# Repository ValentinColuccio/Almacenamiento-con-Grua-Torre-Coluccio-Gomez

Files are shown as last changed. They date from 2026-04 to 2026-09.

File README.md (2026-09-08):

<div align="center">

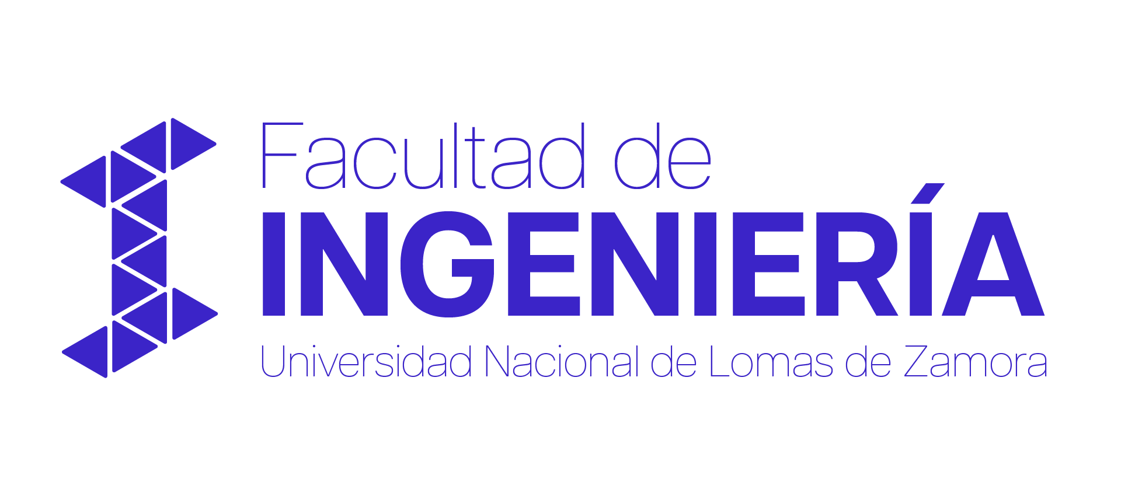
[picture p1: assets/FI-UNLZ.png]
Logo FI UNLZ


<h2 align="center">Facultad de Ingeniería – Universidad Nacional de Lomas de Zamora</h2>

# 🏗️ Grúa Torre Robótica Inteligente

### Proyecto Final de Carrera | Ingeniería en Mecatrónica





</div>

---

> 📄 **[Leé primero el Brief](Doc/Brief.md)** — de qué se trata el proyecto y
> cuál es su finalidad, explicado sin contenido técnico.

---

## 📑 Índice

- [🧠 Descripción General](#-descripción-general)
- [📸 Galería y Demostraciones](#-galería-y-demostraciones)
- [🚀 Arquitectura del Sistema](#-arquitectura-del-sistema)
- [🔍 Decisiones de Ingeniería](#-decisiones-de-ingeniería)
- [💰 Costos del Proyecto](#-costos-del-proyecto)
- [🔌 Hardware y Esquema de Conexiones](#-hardware-y-esquema-de-conexiones)
- [📡 Protocolos de Comunicación](#-protocolos-de-comunicación)
- [📐 Cinemática y Control Embebido](#-cinemática-y-control-embebido)
- [⚙️ Funcionalidades Clave](#️-funcionalidades-clave)
- [🛠️ Tecnologías Utilizadas](#️-tecnologías-utilizadas)
- [📂 Estructura del Repositorio](#-estructura-del-repositorio)
- [🙏 Agradecimientos](#-agradecimientos)
- [👤 Autores](#-autores)

---

## 🧠 Descripción General

Este repositorio contiene el desarrollo integral (software, hardware, planos y documentación) de una **grúa torre robótica a escala**, presentada como Proyecto Final de Carrera para la carrera de **Ingeniería en Mecatrónica** en la Universidad Nacional de Lomas de Zamora (UNLZ).

El sistema simula un entorno logístico automatizado de alta complejidad. Integra hardware embebido, modelado cinemático tridimensional e Inteligencia Artificial distribuida para lograr un ciclo autónomo de:

1. **Percepción:** Detección y clasificación de objetos en tiempo real mediante visión artificial.
2. **Decisión:** Reconocimiento de comandos de voz e interpretación de órdenes, y gestión lógica de inventario.
3. **Actuación:** Movimiento coordinado de precisión para la manipulación, almacenamiento y entrega de cargas. El diseño mecánico contempla diferentes mecanismos de transmisión, empleando reducción por engranajes para el eje principal (Motor A) y transmisión por cable para el resto de los ejes de la estructura.

> **Evolución Tecnológica:** La arquitectura de control de bajo nivel fue optimizada utilizando un microcontrolador **ESP32** bajo un paradigma de programación estructurada y modular. Esto garantiza una ejecución determinista de tiempo real para el manejo simultáneo de 4 actuadores paso a paso con velocidades independientes.

---

## 📸 Galería y Demostraciones

El proyecto cuenta con un diseño de ingeniería respaldado por modelos CAD y esquemas electrónicos, disponibles en este repositorio.

<div align="center">
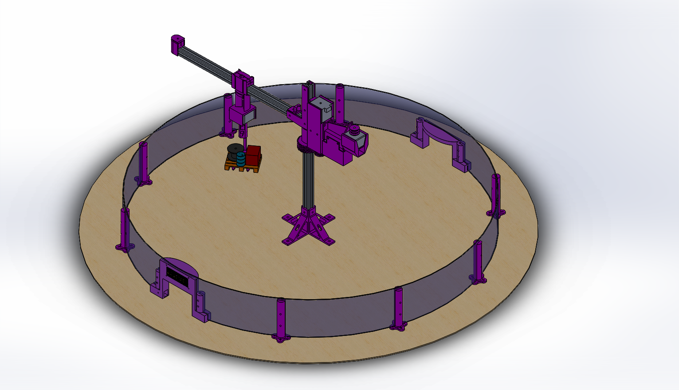
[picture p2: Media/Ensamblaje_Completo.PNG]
Ensamblaje Completo 3D
  
  <br>
  <em>Render del ensamblaje mecánico completo de la grúa torre.</em>
</div>

<br>

<div align="center">
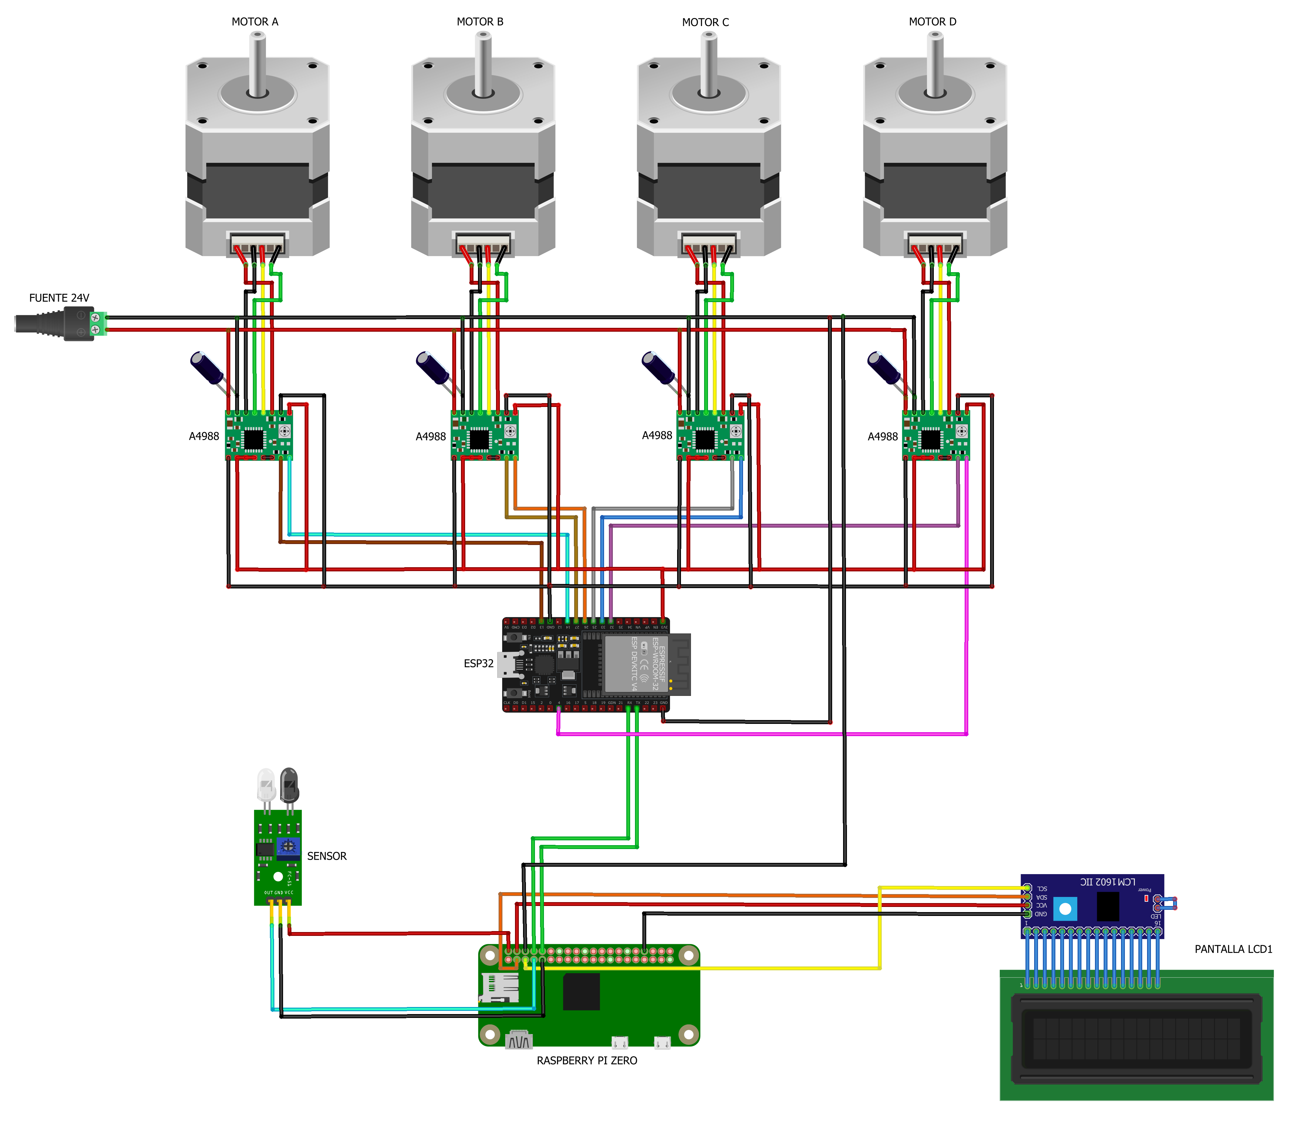
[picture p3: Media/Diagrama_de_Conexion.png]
Esquema Electrónico
  
  <br>
  <em>Esquemático del circuito de potencia y control (Integración de ESP32, Drivers A4988, Raspberry Pi, Sensor, Pantalla LCD).</em>
</div>

<br>

### ⚙️ Modos de Operación Activos

**1. Almacenamiento Automatizado (Visión Artificial)** El sistema detecta e identifica los objetos en el espacio de trabajo para almacenarlos de forma autónoma.

<div align="center">
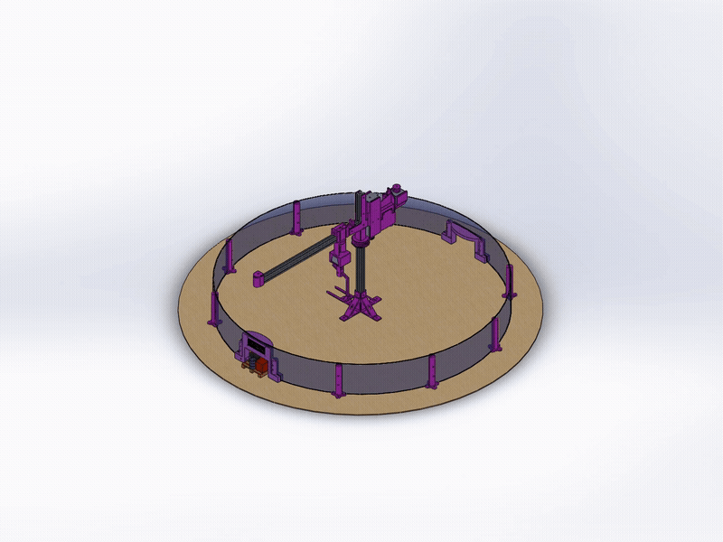
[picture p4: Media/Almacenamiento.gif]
Almacenamiento por Visión Artificial
  
</div>

<br>

**2. Despacho (Reconocimiento de Voz)** Mediante comandos de voz en lenguaje natural, la grúa busca el material solicitado en el inventario y lo despacha dinámicamente hacia la zona de descarga.

<div align="center">
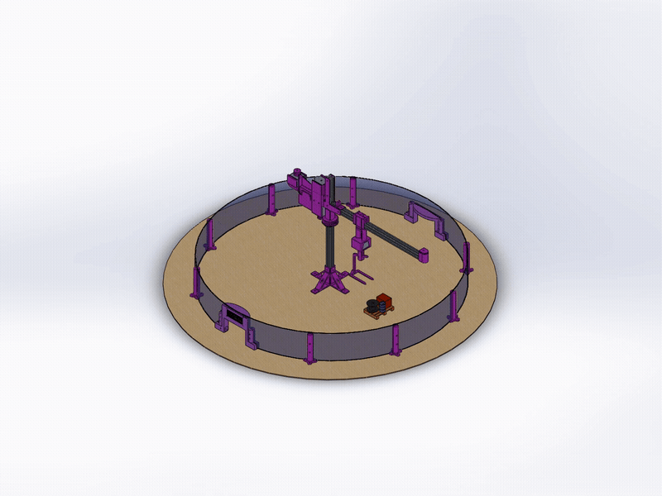
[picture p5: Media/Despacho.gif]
Despacho por Comando de Voz
  
</div>

<br>

> **🎬 Video Completo:** La simulación íntegra y en alta resolución de todo el proceso logístico está disponible en el repositorio. [Haz clic aquí para ver o descargar Animacion_Completa.mp4](Media/Animacion_Completa.mp4).

---

## 🚀 Arquitectura del Sistema

El proyecto implementa un modelo de computación distribuida y *Edge Computing*, segmentando las tareas críticas según la capacidad de cómputo:

<div align="center">
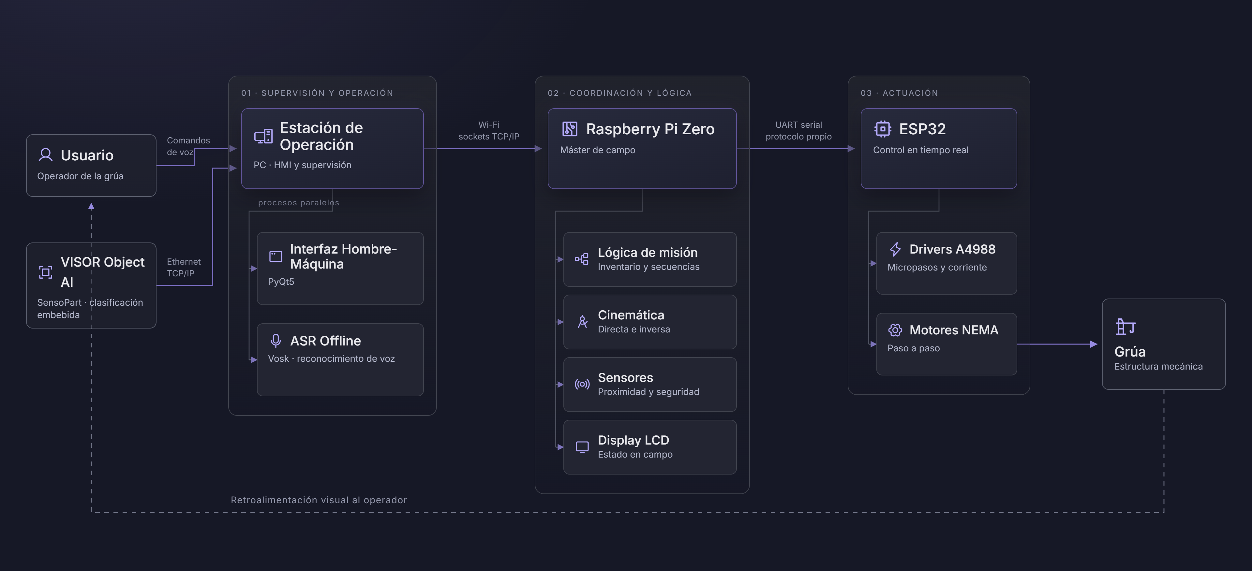
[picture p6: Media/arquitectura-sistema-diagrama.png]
Arquitectura del sistema
  
  <br>
  <em>Arquitectura del sistema</em>
</div>

### Flujo de Trabajo Operativo

1. **Supervisión y Percepción (Estación de Operación):** Aloja el HMI, opera el sensor de visión por disparo bajo demanda y ejecuta el reconocimiento del habla en procesos paralelos (*multiprocessing*). Traduce las intenciones del usuario y envía comandos lógicos a la estación de campo.
2. **Coordinación de Campo (Raspberry Pi):** Gestiona el inventario, interactúa con sensores y traduce las coordenadas espaciales cartesianas a coordenadas angulares y lineales.
3. **Actuación Dedicada (ESP32):** Recibe de forma secuencial las coordenadas parametrizadas y genera los trenes de pulsos precisos para los drivers de potencia de los motores A, B, C y D.

---

## 🔍 Decisiones de Ingeniería

### Subsistema de visión

La identificación de piezas se resolvía originalmente con un modelo propio
(TensorFlow Lite + OpenCV) ejecutado en la estación de operación sobre la
imagen de un teléfono celular. Fue reemplazado por un sensor de visión
industrial **SensoPart VISOR Object AI**, con clasificador embebido en el
propio dispositivo.

Ambas soluciones clasifican mediante aprendizaje automático: lo que cambió es
la plataforma de ejecución y la cadena de adquisición. Como la pieza se
deposita siempre en la misma posición y el subsistema solo determina de qué
pieza se trata, el margen de mejora no estaba en el modelo sino en la
repetibilidad de la imagen de entrada. El teléfono aplica ajustes automáticos
que no pueden desactivarse; el sensor industrial, con iluminación y óptica
fijas, elimina esa variabilidad en el origen en lugar de compensarla.

El sensor entrega la clase por Ethernet TCP/IP a la estación de operación —la
Raspberry Pi Zero no dispone de interfaz Ethernet—, que la traduce en una orden
de misión hacia campo.

📄 [`Doc/Justificacion-Subsistema-Vision.md`](Doc/Justificacion-Subsistema-Vision.md)

## 💰 Costos del Proyecto

Valores de reposición a precio de mercado actual. Conversión a razón de
**1.520 ARS/USD**. No se imputan la estación de operación (PC), el micrófono ni
la tarjeta microSD, por tratarse de equipamiento preexistente del equipo.

### Electrónica y Control

| Componente | Cant. | Unit. (ARS) | Subtotal (ARS) | Subtotal (USD) |
| :--- | :---: | ---: | ---: | ---: |
| Raspberry Pi Zero 2 W | 1 | 45.000 | 45.000 | 29,61 |
| Microcontrolador ESP32 DevKit | 1 | 12.000 | 12.000 | 7,89 |
| Driver de motor paso a paso A4988 | 4 | 3.705 | 14.820 | 9,75 |
| Regulador conmutado step-down LM2596 | 4 | 6.000 | 24.000 | 15,79 |
| Fuente switching 24 V – 15 A | 1 | 19.199 | 19.199 | 12,63 |
| Sensor infrarrojo de proximidad | 1 | 2.500 | 2.500 | 1,64 |
| Display LCD 16×2 con módulo I2C | 1 | 9.000 | 9.000 | 5,92 |
| Cableado, borneras y conexionado | — | — | 15.000 | 9,87 |
| **Subtotal** | | | **141.519** | **93,10** |

### Actuadores

| Componente | Cant. | Unit. (ARS) | Subtotal (ARS) | Subtotal (USD) |
| :--- | :---: | ---: | ---: | ---: |
| Motor paso a paso NEMA 17 (ejes A y B) | 2 | 22.000 | 44.000 | 28,95 |
| Motor paso a paso NEMA 17 pancake (ejes C y D) | 2 | 20.018 | 40.036 | 26,34 |
| **Subtotal** | | | **84.036** | **55,29** |

### Estructura y Mecánica

| Componente | Cant. | Unit. (ARS) | Subtotal (ARS) | Subtotal (USD) |
| :--- | :---: | ---: | ---: | ---: |
| Perfilería de aluminio 20×20 | — | — | 40.000 | 26,32 |
| Rodamiento axial | 1 | 16.000 | 16.000 | 10,53 |
| Hilo de nylon para transmisión por cable | — | — | 4.000 | 2,63 |
| Tornillería, insertos y elementos de fijación | — | — | 20.000 | 13,16 |
| **Subtotal** | | | **80.000** | **52,63** |

### Manufactura Aditiva

Los engranajes del eje principal, las poleas de transmisión, los soportes y las
piezas de carga del almacén fueron fabricados por impresión 3D. La primera etapa
de piezas se resolvió mediante servicio tercerizado; a partir de la segunda
iteración del diseño, la fabricación pasó a realizarse con equipamiento propio,
lo que permitió acortar sensiblemente el ciclo de rediseño y prueba.

| Concepto | Subtotal (ARS) | Subtotal (USD) |
| :--- | ---: | ---: |
| Servicio de impresión tercerizado (etapa inicial) | 65.000 | 42,76 |
| Impresión propia — filamento e insumos (etapa posterior) | 20.000 | 13,16 |
| **Subtotal** | **85.000** | **55,92** |

### Sistema de Visión

El sensor de visión industrial **SensoPart VISOR Object AI** fue cedido en
préstamo por eMove Solutions para el desarrollo del proyecto (ver
[Agradecimientos](#-agradecimientos)), por lo que no representa una erogación y
no se imputa al presupuesto.

### Resumen

| Concepto | ARS | USD |
| :--- | ---: | ---: |
| Electrónica y control | 141.519 | 93,10 |
| Actuadores | 84.036 | 55,29 |
| Estructura y mecánica | 80.000 | 52,63 |
| Manufactura aditiva | 85.000 | 55,92 |
| **Costo total del proyecto** | **390.555** | **256,94** |

*Equipamiento no imputado: estación de operación (PC), micrófono, tarjeta
microSD y sensor de visión (cedido en préstamo).*

## 🔌 Hardware y Esquema de Conexiones

Para asegurar la estabilidad del sistema y mitigar ruidos lógicos o caídas de tensión bruscas, todas las referencias de tierra (`GND` de la fuente de alimentación externa, placa de desarrollo ESP32, Raspberry Pi Zero, sensor óptico de proximidad y pantalla LCD) están interconectadas eléctricamente a una única masa común.

### Asignación de Pines - ESP32 (Etapa de Potencia y Drivers)

| Componente | Motor Asociado | Pin STEP | Pin DIR |
| :--- | :--- | :---: | :---: |
| **Driver A4988 (A)** | Brazo (Eje Principal) | GPIO 13 | GPIO 14 |
| **Driver A4988 (B)** | Carro (Traslación) | GPIO 27 | GPIO 26 |
| **Driver A4988 (C)** | Gancho (Subida/Bajada) | GPIO 25 | GPIO 33 |
| **Driver A4988 (D)** | Gancho (Rotación) | GPIO 32 | GPIO 4 |

### Asignación de Pines - Raspberry Pi Zero (Periféricos e Interfaces)

| Componente | VCC (Alimentación) | GND (Tierra) | Señales de Datos / Pines |
| :--- | :---: | :---: | :--- |
| **Sensor de Proximidad** | 5V | Masa Común | OUT ➔ Pin 7 (GPIO 4) |
| **Pantalla LCD (Módulo I2C)** | 5V | Masa Común | SDA ➔ Pin 3 (GPIO 2) <br> SCL ➔ Pin 5 (GPIO 3) |

---
> 📐 La verificación eléctrica y mecánica del diseño —consumo, dimensionamiento
> de la fuente, corrientes en pines críticos, carga admisible y pares
> requeridos— está desarrollada en [Doc/Calculos.md](Doc/Calculos.md).
---
## 📡 Protocolos de Comunicación
 
La transferencia de datos e instrucciones dentro de la arquitectura distribuida se organiza en tres niveles jerárquicos independientes:

1. **Sockets TCP/IP (Sensor de visión ↔ Estación de Operación):** Enlace Ethernet sobre el cual la estación envía el comando de disparo y recibe el telegrama con la clase identificada.
2. **Sockets TCP/IP (PC ↔ Raspberry Pi):** Comunicación inalámbrica bidireccional y asíncrona establecida a través de una red Wi-Fi local. Permite el envío seguro de comandos lógicos de misión y la actualización del estado de inventario en tiempo real.
3. **Protocolo Serial UART Custom (Raspberry Pi ↔ ESP32):** Conexión física directa cableada por hardware a través de los pines dedicados RX/TX. Para una correcta transferencia de tramas de datos sin pérdidas ni corrupción de bytes, las líneas de comunicación se conectan de manera estrictamente cruzada:
   * `PIN TX (Raspberry Pi Zero)` ➔ `PIN RX (ESP32)`
   * `PIN RX (Raspberry Pi Zero)` ➔ `PIN TX (ESP32)`
   
   *Soporte de datos:* El intérprete de comandos del firmware del ESP32 está desarrollado con soporte nativo para procesar valores decimales de alta precisión (por ejemplo, comandos de coordenadas como `A:90.45`), permitiendo un control de posición angular y lineal submilimétrico.

---

## 📐 Cinemática y Control Embebido

### Lógica Secuencial de Fases Independientes
El algoritmo de control embebido ejecuta los movimientos de los 4 actuadores paso a paso siguiendo una estricta máquina de estados con secuencias de fase independientes. Esto previene esfuerzos mecánicos innecesarios y colisiones en el entorno de almacenamiento:
* **Fase 1 (Posicionamiento de Coordenadas Espaciales):** Se calcula la cinemática y se ejecuta el movimiento en paralelo y simultáneo de los motores A (rotación de brazo), B (traslación de carro) y D (giro de gancho). El sistema bloquea cualquier otra acción hasta que estos tres actuadores hayan alcanzado su posición de destino de forma precisa.
* **Fase 2 (Manipulación y Elevación):** Una vez concluida y confirmada la Fase 1, el sistema habilita de forma aislada e independiente el movimiento del Motor C para controlar el descenso o ascenso del gancho de carga.

*Optimización Dinámica:* Con el objetivo de mejorar el rendimiento visual, la velocidad de respuesta en las demostraciones y garantizar una traslación directa, la lógica de control del firmware prescinde por completo del uso de rampas de aceleración y desaceleración en los trenes de pulsos de los motores paso a paso.

### Firmware Embebido Modular
El código fuente en C++ estructurado para el entorno del **ESP32** rompe con el esquema de script único y se organiza de forma modular y desacoplada:
* **Módulo Principal (`Main.ino`):** Administra el lazo de ejecución principal, la inicialización de periféricos y el parseo continuo del buffer del puerto serial.
* **Módulo de Configuración (`Config.cpp / .h`):** Centraliza de manera ordenada la asignación de GPIOs, constantes de paso, mapeos de hardware y variables globales.
* **Módulo de Control de Motores (`Motor.cpp / .h`):** Implementa la lógica orientada a objetos para la manipulación simultánea de los actuadores mediante la generación de pulsos (STEP) y dirección (DIR) con perfiles de velocidad inyectables en tiempo real.

---

## ⚙️ Funcionalidades Clave

- **Interfaz Hombre-Máquina (HMI):** Aplicación de escritorio desarrollada en
  PyQt5 que centraliza la operación y supervisión del sistema, organizada en
  tres pestañas:
  - *GLOBAL:* visualización en vivo de la imagen del sensor de visión y consola
    unificada de eventos, con diferenciación por color según el nodo de origen
    (estación de operación, estación de campo o interfaz).
  - *Control PC:* arranque y detención supervisada del proceso de percepción y
    comunicaciones que se ejecuta en la estación de operación.
  - *Raspberry / SSH:* establecimiento de sesión SSH interactiva con la estación
    de campo, puesta en marcha y detención remota de su software de control, y
    envío directo de comandos a la consola del dispositivo.

  Una barra de estado permanente informa la disponibilidad de los cinco
  elementos del sistema: estación de operación, sensor de visión, enlace de
  sockets, estación de campo y controlador de tiempo real.

- **Clasificación de Piezas por Visión Industrial:** Identificación de la pieza
  depositada en la estación de entrada mediante sensor **SensoPart VISOR
  Object AI**, con detector de clasificación por aprendizaje ejecutado de forma
  embebida en el propio dispositivo e iluminación integrada. El sensor opera por
  disparo bajo demanda: la estación de operación envía el comando de trigger y
  recibe la clase identificada como telegrama por Ethernet TCP/IP.

- **Disparo Automático del Ciclo de Almacenamiento:** El ciclo no lo inicia el
  operador sino un sensor infrarrojo instalado en la estación de entrada,
  gestionado por la estación de campo mediante detección por flanco con
  antirrebote y tiempo de inhibición, evitando disparos espurios y repetidos.

- **Reconocimiento Automático del Habla (ASR Offline):** Transcripción de
  comandos de voz en español ejecutada localmente mediante la API de Vosk, sin
  requerir conexión a internet. Incorpora palabra de activación, de modo que el
  sistema solo interpreta como orden la locución inmediatamente posterior a
  ella, reduciendo activaciones involuntarias por conversación ambiente.

- **Gestión de Inventario y Asignación de Posiciones:** Registro de ocupación
  del almacén mantenido por la estación de campo, con dos posiciones asignadas
  por tipo de pieza. El sistema resuelve automáticamente la posición libre de
  destino en el almacenamiento y la posición ocupada de origen en el despacho,
  y rechaza la orden informando por pantalla cuando no hay espacio disponible o
  cuando no existe la pieza solicitada.

- **Arquitectura de Ejecución Concurrente:** La estación de operación emplea
  procesos independientes (*multiprocessing*) para la interacción con el sensor
  de visión, el reconocimiento de voz y el despacho de mensajes, con
  comunicación entre ellos por colas. La estación de campo emplea hilos
  (*multithreading*) para la atención del socket, la escucha del controlador de
  tiempo real, el sensor de disparo, la supervisión de red y la ejecución de
  secuencias.

- **Supervisión de Enlace y Recuperación Automática:** La estación de campo
  verifica periódicamente la presencia de la estación de operación en la red y,
  ante la pérdida sostenida del enlace, reinicia automáticamente su interfaz
  inalámbrica. Los sockets implementan reconexión automática en ambos extremos.
---

## 🛠️ Tecnologías Utilizadas
| Capa del Proyecto | Tecnologías y Herramientas |
| --- | --- |
| **Interfaz y Supervisión** | Python 3.9+, PyQt5, QtWebEngine, Paramiko (SSH), Multiprocessing, QThread. |
| **Visión Artificial** | SensoPart VISOR Object AI, SensoPart Configuration Studio, Telegramas sobre sockets TCP/IP. |
| **Procesamiento de Voz** | API Vosk (Modelo en Español), sounddevice, Palabra de activación e intérprete de comandos. |
| **Procesamiento de Campo** | Raspberry Pi OS, Python (threading, queue), Sockets TCP/IP, RPi.GPIO, RPLCD (I2C), Álgebra Matricial. |
| **Control en Tiempo Real** | C++, Framework Arduino / ESP-IDF, UART 115200 bps, Protocolo de tramas propio, Arquitectura Modular. |
| **Hardware y Potencia** | ESP32, Drivers A4988, Motores Paso a Paso NEMA, regulador step Down LM2596, Sensor IR, Display LCD 16×2 I2C. |
| **Diseño e Ingeniería** | SolidWorks (Modelado CAD 3D), Planos Técnicos, Parámetros DH. |

---

---

## 📂 Estructura del Repositorio

```bash
.
├── 📂 Datasheets/     # Hojas de datos técnicas de componentes (ESP32, NEMA, A4988, sensores).
├── 📂 Diseños/        # Archivos CAD originales, piezas 3D y elementos para manufactura.
├── 📂 Doc/            # Documentación de Ingeniería: cálculos, memoria técnica y tesis del PFC.
├── 📂 Media/          # Recursos multimedia utilizados en la documentación.
├── 📂 Planos/         # Planos constructivos mecánicos con vistas normalizadas y diagramas eléctricos.
├── 📂 Scripts/        # Scripts de software secundarios para pruebas de UART, red y calibración de motores.
├── 📂 assets/         # Archivos utilizados en el documento principal de presentación
└── 📄 README.md       # Documento principal de presentación del repositorio.
```
---

## 🙏 Agradecimientos

El desarrollo de este proyecto contó con la colaboración de terceros cuyo aporte
excedió lo estrictamente material y permitió elevar el alcance técnico del
trabajo:

**eMove Solutions** — empresa en la que se desempeña profesionalmente uno de los
autores. Se agradece la cesión en préstamo del sensor de visión industrial
SensoPart VISOR Object AI, y el acceso facilitado a equipamiento y tecnologías de
aplicación industrial real. Esa disponibilidad permitió sustituir una solución de
prototipo por un componente de campo calificado y abordar el subsistema de visión
con criterios de ingeniería industrial, algo difícil de alcanzar en el marco de un
proyecto académico.

<div align="center">
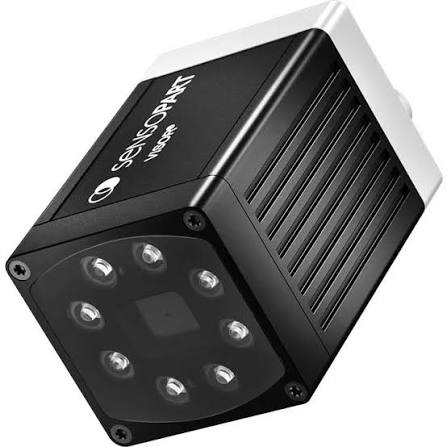
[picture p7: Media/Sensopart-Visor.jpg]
Sensor de visión industrial SensoPart VISOR Object AI
  
  <br>
  <sub><i>Sensor de visión SensoPart VISOR Object AI</i></sub>
</div>

**IDEA3D Impresiones** — por la asistencia en la fabricación de las primeras
piezas del prototipo mediante impresión 3D, durante la etapa inicial de
desarrollo mecánico.

---

## 👤 Autores

Proyecto de fin de carrera desarrollado por los estudiantes de la Facultad de Ingeniería de la UNLZ:

<div align="center">

| **Valentín Coluccio** | **Franco Gómez** |
| :---: | :---: |
|  |  |
|  |  |

---

_Desarrollado con pasión, curiosidad y muchas pruebas y errores 🚀_

</div>

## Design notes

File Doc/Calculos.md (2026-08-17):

# Cálculos de diseño

Verificación eléctrica y mecánica del prototipo.

---

## 1. Datos de partida

### Actuadores

Motor paso a paso bipolar **JK42HS48-1684-08AF** (NEMA 17), cuatro unidades:

| Parámetro | Símbolo | Valor |
|---|---|---|
| Tensión nominal | V_n | 2,8 V |
| Corriente por fase | I_f | 1,68 A |
| Resistencia por fase | R_f | 1,65 Ω |
| Inductancia por fase | L_f | 2,8 mH |
| Par de retención | T_h | 5,0 kg·cm = 0,49 N·m |
| Par de detención | T_d | 260 g·cm = 0,0255 N·m |
| Inercia del rotor | J_r | 68 g·cm² = 6,8×10⁻⁶ kg·m² |
| Configuración | — | Bipolar, 4 hilos |

> **Nota:** los ejes C y D montan motores NEMA 17 *pancake*, de menor par y menor
> corriente nominal (típicamente 1,0 A y 0,15 N·m). El cálculo eléctrico se
> realiza con los datos del motor de mayor consumo para los cuatro ejes, de modo
> que los resultados constituyen una **cota superior conservadora**.

### Etapa de potencia

- Drivers **A4988**, uno por eje, en micropaso **1/16** con ambas fases excitadas.
- Fuente conmutada **24 V / 15 A** (360 W), dedicada exclusivamente a motores.
- ESP32 y Raspberry Pi Zero con fuentes independientes.

### Cinemática de los ejes

| Eje | Función | Transmisión | Radio efectivo |
|---|---|---|---|
| A | Giro del brazo | Engranajes, relación 1:2 | — |
| B | Traslación del carro | Polea Ø20 mm | 10 mm |
| C | Izaje del gancho | Polea Ø20 mm | 10 mm |
| D | Rotación del gancho | Directa | — |

### Geometría

| Magnitud | Valor |
|---|---|
| Altura hasta la pluma | 320 mm |
| Altura máxima de la estructura | 450 mm |
| Longitud de la pluma, del eje a la punta | 450 mm |
| Longitud de la contrapluma | 200 mm |
| Radio mínimo del carro | 75 mm |
| Radio máximo del carro | 200 mm |
| Carrera vertical útil | 100 mm |

---

## 2. Cálculos eléctricos

### 2.1 Consumo por motor

En micropaso, el driver regula las corrientes de fase según

$$i_A = I_f \cos\theta \qquad i_B = I_f \sin\theta$$

de modo que el **módulo del vector de corriente permanece constante** e igual a
I_f, independientemente de la posición dentro del ciclo eléctrico. La pérdida en
el cobre resulta entonces constante:

$$P_{Cu} = R_f \left( i_A^2 + i_B^2 \right) = R_f \, I_f^2$$

$$P_{Cu} = 1{,}65 \times 1{,}68^2 = 4{,}66 \ \mathrm{W} \ \text{por motor}$$

Este valor **no depende de si el motor gira o está detenido manteniendo
posición**: es la característica distintiva del motor paso a paso y la razón por
la que el consumo en reposo coincide con el consumo en régimen.

La potencia mecánica entregada es despreciable frente a este valor. Para el eje
de izaje, con 0,13 kg elevados a 20 mm/s:

$$P_{mec} = m \, g \, v = 0{,}13 \times 9{,}81 \times 0{,}02 = 0{,}026 \ \mathrm{W}$$

es decir, el **0,6 %** de la pérdida en el cobre.

### 2.2 Disipación en los drivers

El A4988 presenta una resistencia de conducción total, sumando rama alta y rama
baja, de aproximadamente 0,64 Ω. Aplicando el mismo razonamiento vectorial:

$$P_{drv} = R_{DS(on)} \, I_f^2 = 0{,}64 \times 1{,}68^2 = 1{,}81 \ \mathrm{W} \ \text{por driver}$$

### 2.3 Balance de potencia y dimensionamiento de la fuente

Los cuatro motores permanecen excitados de forma permanente, por lo que el
consumo es constante y no depende de cuántos ejes se muevan simultáneamente:

| Concepto | Cantidad | Potencia |
|---|---|---|
| Pérdida en cobre de motores | 4 | 18,64 W |
| Disipación en drivers | 4 | 7,24 W |
| Consumo lógico de los drivers (VDD) | 4 | 0,07 W |
| Potencia mecánica útil | — | ≈ 0,03 W |
| **Total** | | **≈ 26 W** |

Corriente demandada a la fuente de 24 V:

$$I_{24V} = \frac{26}{24} \approx 1{,}08 \ \mathrm{A}$$

Agregando un 20 % por pérdidas en el hierro, conmutación y transitorios de
arranque:

$$I_{dise\tilde{n}o} \approx 1{,}3 \ \mathrm{A} \qquad P_{dise\tilde{n}o} \approx 31 \ \mathrm{W}$$

**Verificación:** la fuente instalada entrega 15 A. El factor de utilización es
del **8,7 %**, con un margen superior a once veces la demanda. La fuente está
sobredimensionada respecto del requerimiento estricto; una unidad de 24 V / 3 A
cubriría el consumo con más del doble de margen. La selección se justifica por
disponibilidad y por reserva de capacidad ante ampliaciones, no por necesidad de
corriente.

### 2.4 Ajuste de corriente de los drivers

La corriente de recorte del A4988 se fija mediante el potenciómetro de
referencia:

$$I_{max} = \frac{V_{ref}}{8 \, R_S}$$

Para las placas con resistencia de sensado de 0,1 Ω:

| Corriente deseada | V_ref |
|---|---|
| 1,68 A (nominal del motor) | 1,344 V |
| 1,20 A (recomendada) | 0,960 V |

**Se recomienda limitar la corriente a 1,2 A.** Los cálculos mecánicos de la
sección 4 muestran márgenes de par superiores a treinta veces en todos los ejes,
de modo que la reducción no compromete el funcionamiento. El beneficio térmico es
sustancial:

| | A 1,68 A | A 1,20 A | Reducción |
|---|---|---|---|
| Pérdida en cobre (4 motores) | 18,64 W | 9,50 W | −49 % |
| Disipación en drivers (4) | 7,24 W | 3,69 W | −49 % |
| Corriente de fuente | 1,08 A | 0,55 A | −49 % |

A 1,68 A cada A4988 disipa 1,81 W, valor que exige disipador y ventilación
forzada. A 1,20 A la disipación baja a 0,92 W, dentro de lo que la placa maneja
con disipador adhesivo y convección natural.

### 2.5 Desacoplamiento

El A4988 requiere un condensador electrolítico de 47 a 100 µF conectado entre
VMOT y GND, físicamente próximo a cada driver, para absorber los picos de
corriente de conmutación. Sin él, los transitorios sobre la línea de 24 V pueden
superar la tensión máxima del integrado. Se complementa con un cerámico de
100 nF en paralelo.

---

## 3. Verificación de pines

### 3.1 ESP32

| Pin | Destino | Corriente |
|---|---|---|
| GPIO 13, 14 | Driver A (STEP, DIR) | ≤ 10 µA c/u |
| GPIO 27, 26 | Driver B (STEP, DIR) | ≤ 10 µA c/u |
| GPIO 25, 33 | Driver C (STEP, DIR) | ≤ 10 µA c/u |
| GPIO 32, 4 | Driver D (STEP, DIR) | ≤ 10 µA c/u |
| TX, RX | Enlace UART con Raspberry | despreciable |

Las entradas del A4988 son de tipo CMOS con corriente de fuga máxima de 10 µA.
El consumo total de los ocho pines de control es de **80 µA**, frente a los
12 mA nominales por pin del ESP32: un **0,07 %** del límite.

Componente dinámica por carga capacitiva de entrada, a la frecuencia máxima de
pulsos:

$$I_{din} = C_{in} \, V \, f = 10 \times 10^{-12} \times 3{,}3 \times 3200 = 0{,}1 \ \mu\mathrm{A}$$

También despreciable. **Los pines de control no representan una condición
crítica.**

**Alimentación lógica de los drivers:** el pin de 3,3 V del ESP32 alimenta los
cuatro VDD, con 5 mA típicos cada uno:

$$I_{VDD} = 4 \times 5 = 20 \ \mathrm{mA}$$

El regulador de la placa de desarrollo entrega 800 mA, de los cuales el propio
módulo ESP32 consume hasta 250 mA con la radio desactivada. El margen es amplio.

**Frecuencia de pulsos:** en micropaso 1/16, una vuelta completa requiere
3200 pulsos. Para 1 rev/s el tren es de 3,2 kHz, con período de 312 µs. El tiempo
de establecimiento de corriente en la fase es

$$t_r = \frac{L_f \, I_f}{V_{alim}} = \frac{2{,}8 \times 10^{-3} \times 1{,}68}{24} = 196 \ \mu\mathrm{s}$$

menor que el período disponible, por lo que la corriente alcanza su valor de
consigna en cada micropaso. La relación entre la tensión de alimentación y la
tensión nominal del motor, 24 / 2,8 = 8,6, es la que hace posible ese tiempo de
subida.

### 3.2 Raspberry Pi Zero

Límites del dispositivo: 16 mA por pin, 50 mA en la suma de todos los GPIO,
50 mA en el riel de 3,3 V.

El display y el sensor **se alimentan desde los pines de salida de 5 V de la
Raspberry, no desde los GPIO.** Sobre los GPIO solo circulan las corrientes de
señal.

| Pin | Función | Corriente |
|---|---|---|
| TX, RX | Enlace UART con ESP32 | despreciable |
| GPIO 2 (SDA), GPIO 3 (SCL) | Señal I2C hacia el display | 1,06 mA c/u |
| GPIO 4 | Entrada de la salida del sensor IR | ≈ 0 |
| Salida 5 V | Alimentación del display y del sensor | 45 mA |

Las líneas I2C están cargadas por las resistencias de pull-up del módulo
PCF8574, típicamente de 4,7 kΩ. Cuando la Raspberry impone nivel bajo:

$$I_{sink} = \frac{5}{4700} = 1{,}06 \ \mathrm{mA} \ \text{por línea}$$

El total sobre GPIO es de **2,1 mA**, un 4 % del límite agregado de 50 mA. Sin
observaciones por corriente.

El riel de 3,3 V no alimenta ninguna carga externa, de modo que su límite de
50 mA no está comprometido.

Sobre la salida de 5 V: display 16×2 con retroiluminación, 25 mA; sensor
infrarrojo con LED emisor, 20 mA. El total de 45 mA se suma a los
aproximadamente 150 mA de la propia Raspberry Pi Zero. Una fuente de 5 V / 1 A
resulta suficiente; se adopta 5 V / 2 A por margen de arranque.

### 3.3 Observación crítica: compatibilidad de niveles lógicos

Los GPIO de la Raspberry Pi operan a 3,3 V y **no toleran 5 V**: no incorporan
diodos de protección hacia el riel de alimentación, por lo que la tensión máxima
admisible en una entrada es de aproximadamente 3,3 V. Dos señales del diseño
actual la superan, como consecuencia de que ambos periféricos se alimentan a
5 V.

**a) Salida del sensor infrarrojo.** El módulo entrega su salida digital a nivel
de su alimentación, es decir, 5 V sobre GPIO 4.

*Corrección:* divisor resistivo de 10 kΩ y 15 kΩ.

$$V_{out} = 5 \times \frac{15}{10 + 15} = 3{,}0 \ \mathrm{V}$$

La corriente por el divisor es de 5 / 25 kΩ = 0,2 mA. El nivel de 3,0 V supera
holgadamente el umbral de entrada alta de la Raspberry, de 1,8 V.

**b) Líneas I2C del display.** El módulo PCF8574 alimentado a 5 V mantiene SDA y
SCL en reposo a 5 V a través de sus resistencias de pull-up.

*Correcciones posibles, en orden de preferencia:*

1. Alimentar el módulo I2C a 3,3 V. Es la solución más simple, ya que el PCF8574
   opera desde 2,5 V. Contrapartida: la retroiluminación pierde brillo y el
   contraste requiere reajuste.
2. Intercalar un adaptador de niveles bidireccional, tipo BSS138, que preserva el
   brillo pleno del display.
3. Retirar las resistencias de pull-up del módulo y alimentar únicamente su
   circuito lógico a 3,3 V, dejando la retroiluminación a 5 V.

El circuito puede estar operando correctamente pese a la sobretensión, ya que es
una condición frecuente que no siempre produce falla inmediata, pero constituye
una operación fuera de especificación que degrada el dispositivo y debe
corregirse o, como mínimo, quedar documentada como desviación conocida.

---

## 4. Cálculos mecánicos

### 4.1 Distribución de masas

La disposición constructiva concentra tres de los cuatro motores sobre la
contrapluma, junto con un contrapeso. El cuarto motor, correspondiente al eje D,
va montado sobre el conjunto que desciende con el gancho.

| Elemento | Masa [kg] | Posición x respecto del eje de giro [m] |
|---|---|---|
| Torre, base y corona de giro | 1,60 | 0 |
| Pluma, tramo delantero (0,45 m) | 0,242 | +0,225 |
| Contrapluma, tramo trasero (0,20 m) | 0,108 | −0,100 |
| Motores A, B y C | 0,96 | −0,120 |
| Contrapeso | 0,40 | −0,180 |
| Carro | 0,15 | +R |
| Gancho más motor D | 0,23 | +R |
| **Masa total en vacío** | **3,69** | |

El signo positivo corresponde al lado de trabajo y el negativo al lado de la
contrapluma. La masa de la pluma se obtiene suponiendo densidad lineal uniforme
de 0,538 kg/m sobre los 0,65 m totales, con el centro de gravedad de cada tramo
en su punto medio.

Restantes hipótesis de cálculo:

| Magnitud | Símbolo | Valor |
|---|---|---|
| Masa de la pieza más pesada | m_q | 0,10 kg |
| Semiancho de la base | a | 0,10 m |
| Coeficiente de rozamiento en guías | μ | 0,30 |
| Coeficiente de seguridad al vuelco | n_v | 1,5 |

El coeficiente de rozamiento es el habitual para PLA sobre PLA sin lubricación, y
el coeficiente de seguridad al vuelco es el que se adopta usualmente en el
análisis estático de grúas.

### 4.2 Equilibrio del conjunto giratorio

Antes de analizar la estabilidad de la máquina completa corresponde verificar el
equilibrio de la parte que gira, tomando momentos respecto del eje de giro. Este
balance determina la solicitación sobre la corona y sobre el engranaje del eje A.

Momento del lado de la contrapluma:

$$M_{cp} = \left( 0{,}108 \times 0{,}100 + 0{,}96 \times 0{,}120 + 0{,}40 \times 0{,}180 \right) g = 1{,}942 \ \mathrm{N \cdot m}$$

Momento del lado de trabajo, con el carro en su radio máximo de 0,20 m y sin
carga:

$$M_{tr} = \left( 0{,}242 \times 0{,}225 + 0{,}38 \times 0{,}200 \right) g = 1{,}280 \ \mathrm{N \cdot m}$$

En vacío el conjunto queda desequilibrado hacia la contrapluma en 0,662 N·m. La
carga que produciría el equilibrio exacto en ese radio es

$$Q_{eq} = \frac{0{,}662}{g \times 0{,}200} = 0{,}337 \ \mathrm{kg}$$

es decir, algo más de tres veces la carga nominal de trabajo. **La grúa opera
siempre con predominio del lado de la contrapluma**, condición favorable para la
estabilidad y coherente con el criterio de diseño de las grúas torre reales,
donde el contrapeso se dimensiona para equilibrar aproximadamente un tercio de la
carga nominal.

### 4.3 Carga admisible en función del radio

El comportamiento característico de una grúa torre es que **su capacidad no es un
valor único, sino una función decreciente de la distancia al eje de giro.** El
límite lo impone el momento de vuelco, que es constante, mientras que el brazo de
palanca de la carga crece linealmente con el radio.

Se toman momentos respecto de la arista de vuelco, ubicada a la distancia a del
eje sobre el lado de trabajo. El brazo de palanca de cada masa es la distancia
horizontal que la separa de esa arista.

Momento estabilizador, aportado por las masas situadas del lado de la
contrapluma más el peso propio de la torre:

$$M_{est} = \left( 1{,}60 \times 0{,}100 + 0{,}108 \times 0{,}200 + 0{,}96 \times 0{,}220 + 0{,}40 \times 0{,}280 \right) g = 4{,}952 \ \mathrm{N \cdot m}$$

Momento volcador del tramo delantero de la pluma, cuyo centro de gravedad queda
0,125 m por delante de la arista:

$$M_{pl} = 0{,}242 \times 9{,}81 \times 0{,}125 = 0{,}297 \ \mathrm{N \cdot m}$$

La condición de estabilidad exige que el momento estabilizador, afectado por el
coeficiente de seguridad, supere a la suma de los momentos volcadores:

$$\frac{M_{est}}{n_v} \geq M_{pl} + \left( m_{mov} + Q \right) g \left( R - a \right)$$

donde m_mov es la masa del conjunto móvil, igual a 0,38 kg entre carro, gancho y
motor D. Despejando se obtiene la **ecuación de carga admisible**:

$$Q(R) = \frac{M_{est} / n_v - M_{pl}}{g \left( R - a \right)} - m_{mov}$$

$$Q(R) = \frac{0{,}3062}{R - 0{,}100} - 0{,}38$$

Es una hipérbola desplazada: la carga admisible decae de forma inversamente
proporcional a la distancia entre la carga y la arista de vuelco.

| Radio R [m] | Carga admisible Q [kg] | Coef. de seguridad con 0,10 kg |
|---|---|---|
| 0,150 | 5,74 | 57 |
| 0,200 (radio máximo del carro) | 2,68 | 27 |
| 0,250 | 1,66 | 17 |
| 0,300 | 1,15 | 12 |
| 0,350 | 0,85 | 8,5 |
| 0,400 | 0,64 | 6,4 |
| 0,450 (punta de la pluma) | 0,50 | 5,0 |

Para radios inferiores al semiancho de la base la carga queda del lado interior
de la arista de vuelco y no puede producir volcamiento, por lo que la expresión
deja de tener sentido físico y la capacidad pasa a estar limitada por otros
factores.

El carro opera entre 0,075 y 0,200 m, de modo que **la condición más desfavorable
del ciclo de trabajo real es el radio de 0,200 m**, con capacidad de 2,68 kg y un
margen de veintisiete veces sobre la carga efectiva. Aun extrapolando hasta la
punta de la pluma el margen se mantiene en cinco veces.

El aporte de los tres motores y del contrapeso sobre la contrapluma resulta
decisivo: por sí solos suman 3,17 N·m de los 4,95 N·m del momento estabilizador,
es decir, casi dos tercios del total. **Sin ese lastre la capacidad en el radio
máximo del carro caería aproximadamente a una cuarta parte.**

### 4.4 Verificación por flexión de la pluma

Corresponde comprobar que la estabilidad sea efectivamente el factor limitante y
no la resistencia del material. Suponiendo para la pluma una sección rectangular
hueca de 20 mm de ancho por 25 mm de alto con 3 mm de pared:

$$I = \frac{20 \times 25^3 - 14 \times 19^3}{12} = 18039 \ \mathrm{mm^4} \qquad W = \frac{I}{c} = 1443 \ \mathrm{mm^3}$$

Adoptando para el PLA impreso una tensión admisible de 10 MPa, resultante de
afectar la tensión de rotura por un coeficiente de seguridad de 5 que contempla
la anisotropía propia de la impresión por capas:

$$M_{adm} = \sigma_{adm} \, W = 10 \times 1443 = 14{,}4 \ \mathrm{N \cdot m}$$

El momento flector en el empotramiento, con la carga en la punta de la pluma,
es

$$M_f = \left( Q + 0{,}38 \right) g \times 0{,}45 + 0{,}534$$

Igualando al momento admisible se obtiene una carga límite por flexión de
2,76 kg en la punta, frente a los 0,50 kg que admite el criterio de vuelco.
**La estabilidad gobierna el diseño con un factor de 5,5 sobre la resistencia
del material.**

### 4.5 Par requerido en cada eje

**Eje C — Izaje.** Eleva el conjunto del gancho, que incluye el motor D, más la
carga. Transmisión directa sobre polea de radio 0,010 m:

$$T_C = \left( m_q + m_{gancho+D} \right) g \, r = 0{,}33 \times 9{,}81 \times 0{,}010 = 0{,}0324 \ \mathrm{N \cdot m}$$

**Eje B — Traslación del carro.** Movimiento horizontal: solo debe vencerse el
rozamiento.

$$T_B = \mu \left( m_{mov} + m_q \right) g \, r = 0{,}30 \times 0{,}48 \times 9{,}81 \times 0{,}010 = 0{,}0141 \ \mathrm{N \cdot m}$$

**Eje A — Giro del brazo.** Eje vertical: la gravedad no genera par resistente y
el requerimiento proviene de la inercia. El momento de inercia respecto del eje
de giro incorpora todas las masas del conjunto giratorio, con los tramos de pluma
modelados como barras empotradas en el eje:

$$J = \tfrac{1}{3} m_{pl} L_{pl}^2 + \tfrac{1}{3} m_{cp} L_{cp}^2 + \left( m_{mov} + m_q \right) R^2 + m_{mot} x_{mot}^2 + m_{cpeso} x_{cpeso}^2$$

$$J = 0{,}0163 + 0{,}0014 + 0{,}0192 + 0{,}0138 + 0{,}0130 = 0{,}0637 \ \mathrm{kg \cdot m^2}$$

Con una aceleración angular de 1 rad/s² y relación de transmisión 1:2:

$$T_A = \frac{J \, \alpha}{i} = \frac{0{,}0637 \times 1}{2} = 0{,}0319 \ \mathrm{N \cdot m}$$

**Resumen frente al par disponible:**

| Eje | Par requerido [N·m] | Par de retención [N·m] | Coef. de seguridad |
|---|---|---|---|
| A (giro) | 0,0319 | 0,49 | 15 |
| B (carro) | 0,0141 | 0,49 | 35 |
| C (izaje) | 0,0324 | 0,15 (pancake) | 4,6 |
| D (rotación del gancho) | < 0,005 | 0,15 (pancake) | > 30 |

### 4.6 Conclusiones del análisis mecánico

1. **El factor limitante del sistema es la estabilidad al vuelco**, no la
   resistencia del material ni el par de los motores. La verificación por flexión
   arroja una capacidad 5,5 veces superior a la que admite el criterio de
   estabilidad.

2. **El eje de izaje es el más solicitado en términos relativos**, con un
   coeficiente de seguridad de 4,6. La razón es que debe elevar el motor D junto
   con la carga: el actuador del último grado de libertad se convierte en carga
   del actuador que lo sostiene. Montar el motor D sobre el gancho simplifica la
   transmisión del giro final, pero traslada su masa al eje de izaje, que es
   además el que emplea un motor de menor par. El margen sigue siendo suficiente,
   pero conviene tenerlo presente ante cualquier aumento futuro de la carga
   nominal.

3. **El contrapeso presenta una contrapartida dinámica.** Junto con los tres
   motores aporta casi dos tercios del momento estabilizador, pero también
   duplica el momento de inercia del conjunto giratorio, lo que reduce el
   coeficiente de seguridad del eje A de treinta y cuatro a quince. Es el
   compromiso clásico entre estabilidad estática y respuesta dinámica.

4. Ese margen remanente **es lo que hace viable una decisión de diseño adoptada
   en el firmware**: la ausencia de rampas de aceleración y desaceleración. Un
   accionamiento sin rampas somete al motor al par inercial completo en el
   instante del arranque, lo que habitualmente provoca pérdida de pasos. Con un
   margen de quince veces en el eje más comprometido dinámicamente, el motor
   absorbe ese transitorio sin desincronizarse. La simplificación del control no
   es arbitraria: está respaldada por la reserva de par disponible.

5. La curva de carga admisible obtenida reproduce el comportamiento de una grúa
   torre real, donde la capacidad nominal se especifica siempre asociada a un
   radio determinado. El rango de trabajo del carro se ubica en la zona de la
   curva donde el margen es mayor.

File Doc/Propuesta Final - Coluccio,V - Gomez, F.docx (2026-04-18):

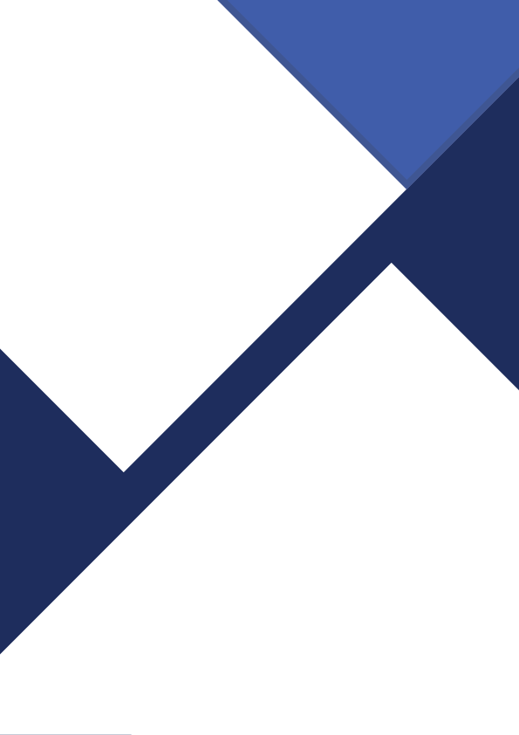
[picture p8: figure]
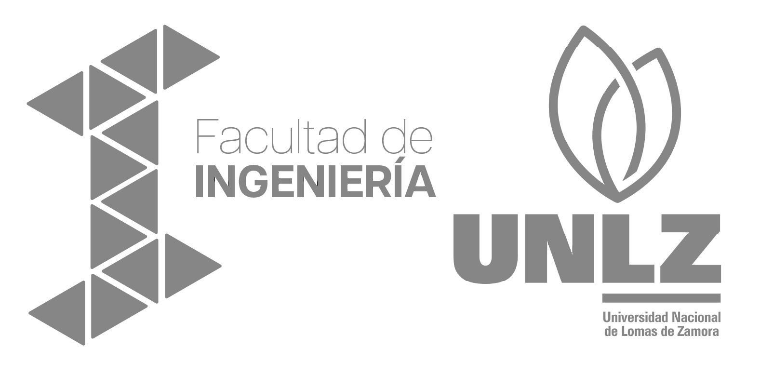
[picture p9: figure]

Facultad de Ingeniería

UNLZ

SISTEMA AUTOMATIZADO DE CLASIFICACIÓN Y DESPACHO CON GRÚA PLUMA ROBOTIZADA

Cátedra: Proyecto en Ingeniería Mecatrónica

Docentes: Blanca, Ezequiel

Lukaszewicz, Cristian

Szombach, Juan

Alumnos: Coluccio, Valentin – 43.867.235

Gomez, Franco Gabriel – 41.451.020

1°C-2025

PROPUESTA FINAL

Título del Proyecto.

Sistema Automatizado de Clasificación y Despacho con Grúa Pluma Robotizada

Motivación y/o antecedentes.

En entornos industriales y logísticos, la organización y distribución eficiente de productos es fundamental para optimizar tiempos y reducir errores. Actualmente, muchos procesos de almacenamiento y despacho requieren intervención manual y/o de robots autónomos que se mueven por el suelo, lo que puede generar demoras y aumentar el riesgo de accidentes laborales. La automatización de estos procesos mediante un sistema robotizado mejora la eficiencia, seguridad y reducción de costos operativos.

Descripción de la propuesta.

La propuesta consiste en el desarrollo de una grúa pluma automatizada como prototipo funcional a escala, con la capacidad de operar en un entorno controlado para el reconocimiento, clasificación, almacenamiento y despacho de diferentes elementos. El sistema estará compuesto por un brazo giratorio con un rango de trabajo circular de 360 grados, y utilizará una cámara para identificar objetos mediante visión artificial. Una vez identificados, estos objetos serán transportados automáticamente por la grúa hacia su sector de almacenamiento correspondiente.

Además, se incorporará una interfaz de usuario por comandos de voz que permitirá solicitar el despacho de elementos específicos. El sistema reconocerá la orden y procederá a entregar el elemento en una zona específica del área de trabajo.

Uno de los aspectos clave de este proyecto es la seguridad operacional. El área donde operará la grúa será completamente cerrada y estará delimitada para evitar el ingreso de personas durante el funcionamiento. Para reforzar esta seguridad, se instalarán sensores de presencia en las zonas de entrada y salida del sistema (recepción de elementos y despacho), que detectarán si una persona ingresa accidentalmente al área de trabajo. En caso de detectar presencia humana, el sistema se detendrá de inmediato y activará un protocolo de seguridad hasta que la zona vuelva a estar libre de obstáculos.

Este enfoque garantiza un entorno seguro para la operación autónoma de la grúa, minimizando el riesgo de accidentes y permitiendo una integración responsable de tecnologías automatizadas en procesos logísticos.

Alcance.

El proyecto se presentará en forma de un prototipo funcional a escala, que incluirá los siguientes aspectos clave:

- Diseño y construcción de la estructura de la grúa pluma.
- Implementación de un sistema de control automatizado para la manipulación y almacenamiento de los objetos, los cuales se podrán diferenciar claramente.
- Integración de una cámara con procesamiento de imagen para la identificación de elementos.
- Implementación de sensores de seguridad y un recinto cerrado para evitar accidentes.
- Desarrollo de un sistema de despacho por reconocimiento de voz.

Selección de docentes para realizar consultas y validar diseños.

- Matias Joel Hirak – Fundamentos de Robótica

Justificación: sus conocimientos en sistemas automatizados y control de robots es clave para el desarrollo del proyecto. La grúa pluma automatizada requiere integración de sensores, visión artificial y sistemas de control, áreas en las que el profesor puede aportar datos valiosos. Además, su experiencia en robótica aplicada permitirá optimizar el diseño del prototipo y garantizar un funcionamiento eficiente y seguro.

- Heidenreich Elvio – Modelado y dinámica de sistemas mecánicos

Justificación: sus conocimientos en mecánica, modelado y programación nos puede orientar en la parte del diseño de la estructura, así como también al momento de implementarla. La grúa pluma requiere de una estabilidad considerable para la correcta manipulación de las piezas, área en la que el profesor nos puede orientar. Además, cuenta con experiencia en diseñar y modelar estructuras mecánicas para diferentes usos.

Especificaciones de Requerimientos

- Requerimientos Funcionales:
- La grúa pluma deberá girar 360° para acceder a todas las áreas de trabajo.
- Deberá contar con una cámara para la detección y clasificación de piezas diferentes, en nuestro caso se tratará de cubos, rombos, esferas, amorfas, y de diferentes colores.
- Se implementará un sistema de control automatizado para la manipulación y almacenamiento.
- Se integrará un sistema de despacho activado por comandos de voz.
- El sistema deberá operar de forma autónoma.
- Se incorporarán sensores de detección de presencia para detener el sistema en caso de ingreso de una persona.
- Requerimientos No Funcionales:
- El área de trabajo contará con un recinto cerrado para garantizar la seguridad.
- La interfaz de usuario deberá ser intuitiva y de fácil uso.

Diseño Funcional

Interfaz de Usuario

- Permite que el usuario interactúe con el sistema, ya sea para realizar pedidos de elementos o monitorear el estado del sistema.

Cámara

- Detecta y clasifica los objetos en la zona de trabajo utilizando visión artificial.

Sensores de Seguridad

- Garantiza que la operación sea segura y detiene el sistema si hay alguna intrusión en el área de trabajo.

PC (Procesamiento Principal)

- Procesa la información proveniente de la cámara, interpreta los comandos de voz y gestiona el sistema en general.

Raspberry (Unidad de Control de Movimiento)

- Recibe órdenes desde la PC y controla los motores de la grúa pluma a través del Arduino.

Arduino (Controlador de Motores)

- Controla directamente los motores de la grúa pluma según las órdenes enviadas por la Raspberry.

Motores de la Grúa Pluma

- Motor 1: Rotación del brazo (360°).
- Motor 2: Movimiento horizontal del carro sobre el brazo.
- Motor 3: Elevación del brazo (subida y bajada).
- Motor 4: Control de la pinza o ventosa para sujetar objetos.

Costos del prototipo:

Componente | Cantidad | Costo Unitario | Costo Total | Proveedor
Microcontrolador Raspberry | 1 | 40.000 | 40.000 | Mercado libre
Microcontrolador Arduino | 1 | 10.000 | 10.000 | Mercado libre
Motor y Driver Principal | 1 | 30.000 | 30.000 | Mercado libre
Motores y Drivers Secundarios | 3 | 8.000 | 24.000 | Mercado libre
Cámara | 1 | 10.000 | 10.000 | Mercado libre
Sensores de proximidad | 2 | 2.000 | 4.000 | Mercado libre
Módulo de reconocimiento de voz | 1 | 8.000 | 8.000 | Mercado libre
Perfil aluminio 20x20 | 1 | 15.000 | 15.000 | Mercado libre
Costo impresiones 3D | - | - | 40.000 | -
Cables | 2 | 3.000 | 6.000 | Mercado libre
Total aproximado en pesos | - | | 183.000 | -
Total aproximado en dólares | - | - | 132 | -

Presupuestos:

- Microcontrolador Raspberry: mercado libre es de los pocos proveedores en argentina. En este caso, se optó por la compra del Raspberry con la opción de los Headers soldados. Las opciones con los Headers no soldados rondaban entre los $36.000 a $37.000.
- Microcontrolador Arduino: mercado libre maneja precios similares entre todas las opciones de venta. También se compararon precios en casas de electrónica, y los precios rondaban alrededor de los $14.000 a $15.000. En nuestro caso ya contamos con el microcontrolador previamente.
- Motor y Driver Principal: se seleccionó un motor con su respectivo driver acorde a su función, es el encargado de mover el brazo de la grúa (360°) y el que mas peso debe soportar. Los precios variaban entre los $25.000 a $45.000, respectivamente por su torque. En nuestro caso ya contamos con el componente previamente.
- Motores y Drivers Secundarios: se trata de los motores y drivers correspondientes a la traslación del carro, a la baja y elevación del gancho y a la función de abrir/cerrar el gancho. Requieren menos esfuerzo que el motor principal, y los precios rondaban entre los $7.000 a $10.000.
- Cámara: se evaluaron opciones que sean compatibles con el microcontrolador. Los precios variaban entre $8.000 a $18.000. Existe la posibilidad de utilizar la cámara de un celular móvil para ahorrar costos.
- Sensores de proximidad: mercado libre maneja precios similares entre todas las opciones de venta, entre $2.000 y $3.000. También se compararon precios en casas de electrónica, en algunos casos no contaban con el componente, los precios rondaban por encima de los $3.000.
- Módulo de reconocimiento de voz: para contar con una buena calidad de toma de audio, se buscó un módulo de micrófono amplificado y los precios eran similares, entre los $8.000 y $8.500.
- Perfil aluminio 20x20: se compararon diferentes precios en relación a la venta por mercado libre con fabricantes y comerciantes zonales, rondaban aproximadamente entre $13.000 y $16.000. Se opto por el perfil con una buena calidad de material y medida necesaria para el proyecto.
- Costo impresiones 3D: se solicitó a un tercero un presupuesto acorde a las impresiones necesarias, como por ejemplo la base, engranajes, carrito, gancho.
- Cables: los precios encontrados en casas de electrónica eran aproximadamente el doble a los de mercado libre, que variaban entre $2.000 y $3.000.

Plazos de entrega de los materiales:

- Microcontrolador Raspberry: 1 – 2 días
- Microcontrolador Arduino: 1 – 2 días
- Motor y Driver Principal: 2 – 3 días
- Motores y Drivers Secundarios: 2 – 3 días
- Cámara: 1 – 2 días
- Sensores de proximidad: 2 – 3 días
- Módulo de reconocimiento de voz: 1 – 2 días
- Perfil aluminio 20x20: 5 – 6 días
- Costo impresiones 3D:
- Cables: 1 – 2 días

TRABAJO PRÁCTICO N° 1 | Informática y Programación Industrial

Página 8 Propuesta Final | Proyecto en Ingeniería Mecatrónica

Universidad Nacional de Lomas de Zamora Facultad de Ingeniería

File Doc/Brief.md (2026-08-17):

# Brief del proyecto

## Almacenamiento y despacho automatizado con grúa torre

**Valentín Coluccio y Franco Gómez**
Ingeniería en Mecatrónica — Universidad Nacional de Lomas de Zamora — 2026

<!-- FOTO 1 → Media/01-vista-general.jpg — la maqueta completa terminada, vista general, bien iluminada. Es la primera imagen que va a ver alguien que entra al repositorio. -->
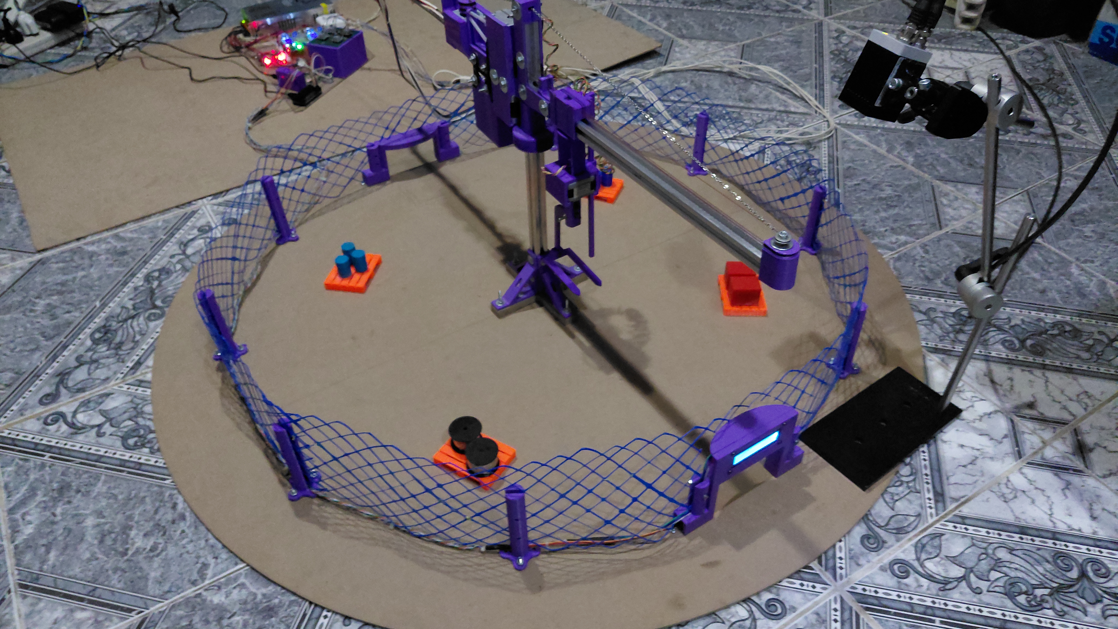
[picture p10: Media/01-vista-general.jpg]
Vista general de la maqueta


---

## De qué se trata

Construimos una maqueta funcional de un depósito automático. Es un depósito sin personas dentro: las cosas entran, el sistema de manera automática las reconoce, las guarda en el lugar que les corresponde, y cuando alguien las necesita, las va a buscar y las trae.

Lo particular es cómo se piden las cosas: **hablándole**. El operador dice en voz alta qué necesita y el sistema se lo alcanza.

La máquina que hace el trabajo físico es una **grúa torre**, la misma que se ve en cualquier obra en construcción, pero acá reducida al tamaño de una maqueta y controlada por una computadora en lugar de por un operario.

---

## Para qué sirve

Guardar cosas parece simple, pero en la industria es un problema caro. Un depósito necesita espacio, techo, estanterías, personal que sepa dónde está cada cosa y que se equivoque lo menos posible. Cuando el depósito crece, encontrar una pieza puede llevar más tiempo que usarla.

La automatización resuelve eso: el sistema nunca se olvida dónde guardó algo, no se confunde una pieza con otra y no necesita que alguien camine hasta el fondo del galpón.

Ahora bien, **este proyecto no busca reemplazar a los depósitos automáticos que ya existen** dentro de un galpón, donde hay soluciones muy buenas y muy probadas. La grúa torre tiene sentido en otro escenario:

- **A la intemperie**, donde construir un techo sobre toda la superficie sería carísimo.
- **En superficies grandes**, donde el alcance de una grúa cubre mucho más terreno que una estantería.
- **Con poca rotación**, es decir, cuando las cosas se guardan por bastante tiempo y no entran y salen todo el día.

Piezas grandes acopiadas al aire libre, materiales de obra, bobinas, contenedores: ahí es donde una grúa torre puede hacer un trabajo que otras máquinas no hacen bien.

---

## Cómo funciona, paso a paso

**1. Llega la pieza.**
Alguien apoya una pieza en la zona de entrada. Un sensor detecta que hay algo ahí.

**2. El sistema la reconoce.**
Una cámara inteligente mira la pieza y decide qué es. No lee un código ni una etiqueta: la reconoce por su forma y su aspecto, igual que lo haría una persona. Puede distinguir entre tipos de piezas distintas, en nuestro caso 4.

**3. La grúa la guarda.**
Sabiendo qué pieza es, el sistema decide en qué lugar del depósito va y le da la orden a la grúa. La grúa gira, se desplaza, baja, la levanta y la deposita en su casillero. Mientras tanto, anota internamente qué hay guardado y dónde.

**4. Alguien la pide, en voz alta.**
Cuando se necesita una pieza, el operador dice "torre" para llamar al sistema y le pide lo que necesita. No hay que tocar una pantalla ni escribir nada: se puede pedir con las manos ocupadas o con guantes puestos.

**5. La grúa la trae.**
El sistema verifica que esa pieza esté efectivamente guardada, va a buscarla y la deja en la zona de salida.

<!-- VIDEO: el ciclo completo, de punta a punta, sin cortes. Es lo que mejor explica el proyecto. Subir el archivo .mp4 arrastrándolo a un issue o comentario de GitHub y pegar acá el enlace que genera, o dejar el enlace a YouTube. -->
🎥 **[Ver el sistema funcionando](https://www.youtube.com/playlist?list=PLAaialL0bhKQ)**

---

## Qué hace falta para que esto funcione

Aunque desde afuera se ve simple, adentro hay tres cosas distintas trabajando en simultáneo y coordinadas entre sí:

- **Ver:** identificar correctamente qué pieza llegó.
- **Escuchar:** entender lo que dice una persona hablando normalmente, incluso con ruido alrededor.
- **Moverse:** llevar la grúa a un punto exacto del espacio, y volver a ese mismo punto todas las veces que haga falta.

Cada una de esas tres partes es un desafío por separado. El trabajo real del proyecto fue lograr que las tres funcionen juntas, al mismo tiempo, sin pisarse y sin equivocarse.

<!-- FOTO 3 → Media/03-detalle-operacion.jpg — un plano cerrado de la grúa levantando o depositando una pieza. Que se vea el detalle mecánico. -->
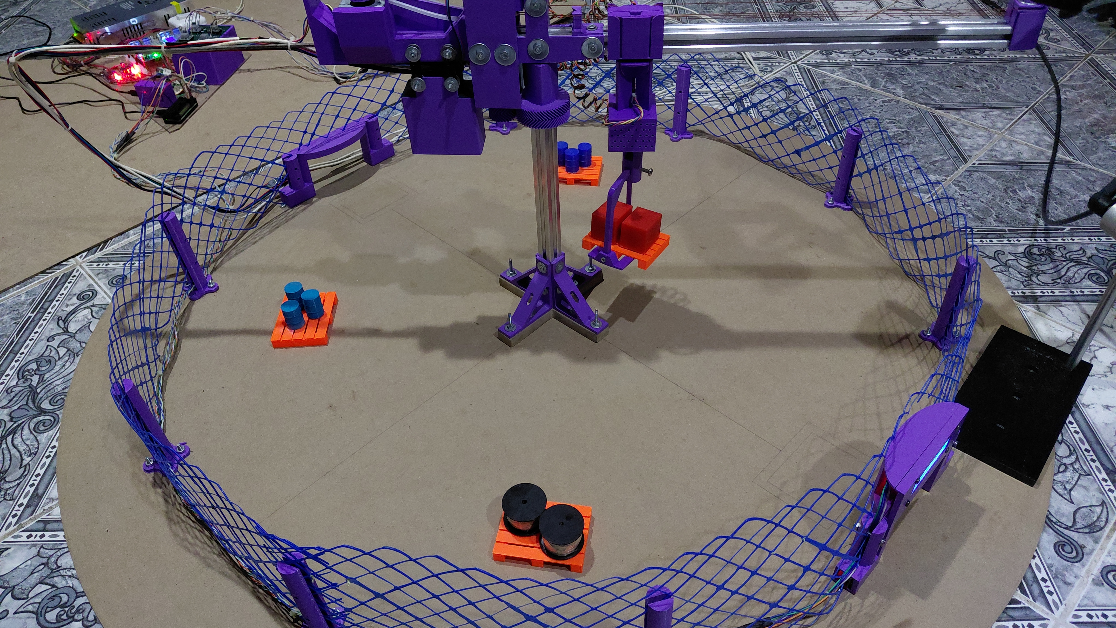
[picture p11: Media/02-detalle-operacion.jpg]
La grúa en operación


---

## Qué se logró

El sistema está construido y funcionando. Reconoce las piezas, entiende las órdenes habladas, guarda, recuerda dónde guardó y despacha lo que se le pide.

Todo el prototipo se construyó con un presupuesto de alrededor de 390.000 pesos argentinos (257 USD) —sin contar la cámara, que fue prestada—, con piezas impresas en 3D y componentes que se consiguen en el mercado local.

---

## Agradecimientos

A **eMove Solutions**, por el préstamo de la cámara industrial.
A **IDEA3D Impresiones**, por las primeras piezas impresas en 3D.

---

📄 La documentación técnica completa está en el [README](../README.md) de este repositorio.

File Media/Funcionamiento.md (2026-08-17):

Link a playlisy de youtube con el funcionamiento:

https://www.youtube.com/playlist?list=PLAaialL0bhKQ

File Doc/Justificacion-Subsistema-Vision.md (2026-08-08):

# Justificación del subsistema de visión artificial

**Proyecto Final de Carrera — Ingeniería en Mecatrónica — FI UNLZ**
Grúa Torre Robótica Inteligente

---

## 1. Función del subsistema

El subsistema de visión cumple una única función dentro del ciclo operativo:
determinar **qué pieza** ha sido depositada en la estación de entrada. Las
clases reconocidas son caja, bidón uno, bidón dos y carrete, además del estado
de estación vacía.

La pieza se coloca siempre en la misma posición y orientación dentro de la
estación de entrada. El subsistema, por lo tanto, no realiza medición de
posición ni cálculo de coordenadas: su salida es la clase de la pieza. La
posición de almacenamiento se resuelve luego por asignación lógica en la
estación de campo, que mantiene un registro de ocupación con dos posiciones
disponibles por tipo de pieza y devuelve la primera libre.

Se trata, en consecuencia, de un problema de **clasificación sobre un conjunto
cerrado de piezas conocidas, en una estación fija y con condiciones de escena
controlables**.

---

## 2. Implementación inicial

La primera versión resolvía la clasificación con un modelo de red neuronal
reentrenado sobre un conjunto de imágenes propio, ejecutado mediante TensorFlow
Lite y OpenCV en la estación de operación. La imagen se adquiría con la cámara
de un teléfono celular.

Esta implementación cumplía la función requerida, pero presentaba tres
limitaciones de fondo:

**Cadena de adquisición no controlada.** El teléfono aplica de forma automática
y no desactivable el ajuste de exposición, el enfoque y el balance de blancos.
La imagen entregada al clasificador variaba según la hora del día y la
iluminación del ambiente. El modelo debía absorber una variabilidad introducida
por el propio instrumento de medición, ajena al problema a resolver.

**Montaje no repetible.** Sin una fijación mecánica normalizada, la distancia y
el ángulo de trabajo no eran reproducibles entre ensayos, lo que agregaba una
fuente de variación independiente de la iluminación.

**Costo de mantenimiento del modelo.** Incorporar una pieza nueva al catálogo
requería ampliar el conjunto de imágenes, reentrenar el modelo y volver a
desplegarlo. Es una tarea que exige conocimiento específico de aprendizaje
automático y que, en un entorno productivo real, no puede resolver el personal
de mantenimiento.

---

## 3. Solución adoptada

Se reemplaza la cámara de teléfono y el modelo propio por un sensor de visión
industrial **SensoPart VISOR Object AI**, que incorpora un detector de
clasificación por aprendizaje ejecutado en el propio dispositivo.

El sensor se entrena presentándole imágenes de muestra de cada clase desde el
software de configuración del fabricante. El algoritmo se ejecuta de forma
embebida, sin requerir conexión a red externa ni servicios en la nube. El
resultado se entrega como telegrama por interfaz Ethernet TCP/IP.

---

## 4. Fundamento de la decisión

Corresponde aclarar en primer término qué **no** cambió. Ambas implementaciones
resuelven la clasificación mediante aprendizaje automático: no se reemplazó
inteligencia artificial por procesamiento clásico de imagen. Lo que se modificó
es la **plataforma de ejecución y la cadena de adquisición**, migrando desde un
montaje de prototipo hacia un componente industrial calificado.

**Control de la escena en el origen.** El sensor integra iluminación propia,
óptica y tiempo de exposición fijos, y montaje mecánico normalizado. Este es el
argumento central de la decisión: dado que la pose de la pieza es fija y la
escena es controlable, el margen de mejora del subsistema no estaba en el
modelo sino en la calidad y la repetibilidad de la imagen de entrada. Al fijar
las condiciones de adquisición, la variabilidad de iluminación deja de existir
como perturbación en lugar de tener que ser compensada por el clasificador.

**Reducción del costo de alta de piezas.** El detector se entrena con unas pocas
imágenes de muestra por clase desde la herramienta de configuración, sin
escribir código. La incorporación de una pieza nueva pasa de ser una tarea de
ingeniería de software a una tarea de configuración, ejecutable por personal
técnico sin formación en aprendizaje automático.

**Descarga de cómputo en la estación de operación.** La estación de operación
deja de ejecutar la inferencia del modelo de visión. Esto libera el proceso que
competía por recursos con el reconocimiento de voz y con la interfaz gráfica,
ejecutados de forma concurrente en el mismo equipo.

**Componente instalable en planta.** El sensor cuenta con grado de protección
industrial, montaje normalizado y soporte para protocolos de comunicación de
campo además de Ethernet TCP/IP. Esto hace que el subsistema sea trasladable a
una arquitectura de automatización real con controlador lógico programable,
condición que un teléfono celular no puede satisfacer.

**Disponibilidad del equipamiento.** El sensor fue facilitado sin cargo para el
desarrollo del proyecto, lo que permitió incorporar un componente de catálogo
industrial sin impacto sobre el presupuesto.

---

## 5. Integración en la arquitectura del sistema

El sensor se comunica con la **estación de operación**, y no directamente con la
estación de campo. La razón es de interfaz física: el sensor entrega su
resultado por Ethernet, y la Raspberry Pi Zero no dispone de interfaz Ethernet.
La estación de operación, que ya se encuentra en la misma red, actúa como nodo
de integración.

Esto es consistente con el rol que dicha estación cumple en el sistema, que no
es el de un nodo de cómputo dedicado a la visión sino el de puesto de
supervisión y operación: aloja la interfaz hombre-máquina, ejecuta el
reconocimiento de voz, concentra las comunicaciones con la estación de campo y
registra el intercambio de mensajes entre todos los nodos.

El sensor opera **por disparo bajo demanda**, no en adquisición continua. La
secuencia es la siguiente:

1. Un sensor infrarrojo en la estación de entrada detecta la presencia de una
   pieza. La estación de campo lo gestiona por detección de flanco con
   antirrebote y tiempo de inhibición, y notifica el evento a la estación de
   operación.
2. La estación de operación envía el comando de disparo al sensor de visión.
3. El sensor clasifica y devuelve la clase identificada por telegrama TCP/IP.
4. La estación de operación traduce la clase en una orden de misión y la remite
   a la estación de campo, que asigna la posición libre y ejecuta el ciclo de
   almacenamiento.

La imagen en vivo del sensor se visualiza en la pestaña de supervisión de la
interfaz hombre-máquina, junto con el registro de eventos de todos los nodos.

La arquitectura resultante responde a una estructura jerárquica de automatización
de tres niveles: actuación en tiempo real, control de campo, y supervisión y
operación. El sensor de visión se incorpora como dispositivo inteligente de
campo cuyo resultado ingresa al sistema por el nivel de supervisión.

---

## 6. Alcance del trabajo propio en el subsistema

- Definición del requerimiento funcional y de las condiciones de operación de la
  estación de entrada.
- Desarrollo de la implementación inicial con modelo propio, que aportó el
  criterio técnico necesario para especificar, configurar y poner a punto
  correctamente el sensor finalmente adoptado.
- Construcción del conjunto de imágenes de entrenamiento y puesta a punto del
  detector de clasificación.
- Diseño del montaje y de las condiciones de iluminación de la estación de
  entrada.
- Implementación del enlace por sockets con el sensor: comando de disparo,
  recepción y validación del telegrama de resultado, y reconexión automática
  ante caída del enlace.
- Integración del resultado con la lógica de misión y con el registro de
  ocupación del almacén.
- Visualización del estado y de la imagen del sensor en la interfaz
  hombre-máquina.

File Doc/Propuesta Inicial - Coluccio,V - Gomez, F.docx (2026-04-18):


Facultad de Ingeniería

UNLZ

Cátedra: Proyecto en Ingeniería Mecatrónica

Docentes: Blanca, Ezequiel

Lukaszewicz, Cristian

Szombach, Juan

Alumnos: Coluccio, Valentin – 43.867.235

Gomez, Franco Gabriel – 41.451.020

PROYECTO EN INGENIERIA MECATRONICA

1°C-2025

PROPUESTA INICIAL

Título del Proyecto.

Sistema Automatizado de Clasificación y Despacho con Grúa Pluma Robotizada

Motivación y/o antecedentes.

En entornos industriales y logísticos, la organización y distribución eficiente de productos es fundamental para optimizar tiempos y reducir errores. Actualmente, muchos procesos de almacenamiento y despacho requieren intervención manual y/o de robots autónomos que se mueven por el suelo, lo que puede generar demoras y aumentar el riesgo de accidentes laborales. La automatización de estos procesos mediante un sistema robotizado mejora la eficiencia, seguridad y reducción de costos operativos.

Descripción de la propuesta.

El proyecto consiste en diseñar y construir un prototipo funcional de una grúa pluma automatizada, que operará en un área de trabajo delimitada y circular. Este sistema contará con una cámara para la detección y clasificación de los elementos recibidos. Mediante algoritmos de procesamiento de imagen e inteligencia artificial, el sistema identificará el tipo de objeto y lo transportará a su sector de almacenamiento correspondiente. Además, existirá un sector de despacho donde la grúa entregará elementos solicitados por el operario a través de un sistema de reconocimiento de voz.

El prototipo se desarrollará con un enfoque en seguridad industrial. Para ello, el área de trabajo estará cercada y contará con sensores de detección de presencia para detener el sistema en caso de ingreso de una persona al área de operación. Así, se garantizará la seguridad del entorno y de los operarios.

Alcance.

El proyecto se presentará en forma de un prototipo funcional a escala, que incluirá los siguientes aspectos clave:

- Diseño y construcción de la estructura de la grúa pluma.
- Implementación de un sistema de control automatizado para la manipulación y almacenamiento de los objetos, los cuales se podrán diferenciar claramente.
- Integración de una cámara con procesamiento de imagen para la identificación de elementos.
- Implementación de sensores de seguridad y un recinto cerrado para evitar accidentes.
- Desarrollo de un sistema de despacho por reconocimiento de voz.

Selección de docentes para realizar consultas y validar diseños.

- Matias Joel Hirak – Fundamentos de Robótica

Justificación: sus conocimientos en sistemas automatizados y control de robots es clave para el desarrollo del proyecto. La grúa pluma automatizada requiere integración de sensores, visión artificial y sistemas de control, áreas en las que el profesor puede aportar datos valiosos. Además, su experiencia en robótica aplicada permitirá optimizar el diseño del prototipo y garantizar un funcionamiento eficiente y seguro.

- Heidenreich Elvio – Modelado y dinámica de sistemas mecánicos

Justificación: sus conocimientos en mecánica, modelado y programación nos puede orientar en la parte del diseño de la estructura, así como también al momento de implementarla. La grúa pluma requiere de una estabilidad considerable para la correcta manipulación de las piezas, área en la que el profesor nos puede orientar. Además, cuenta con experiencia en diseñar y modelar estructuras mecánicas para diferentes usos.

PROPUESTA FINAL

TRABAJO PRÁCTICO N° 1 | Informática y Programación Industrial

Página 8 Propuesta Inicial | Proyecto en Ingeniería Mecatrónica

Universidad Nacional de Lomas de Zamora Facultad de Ingeniería

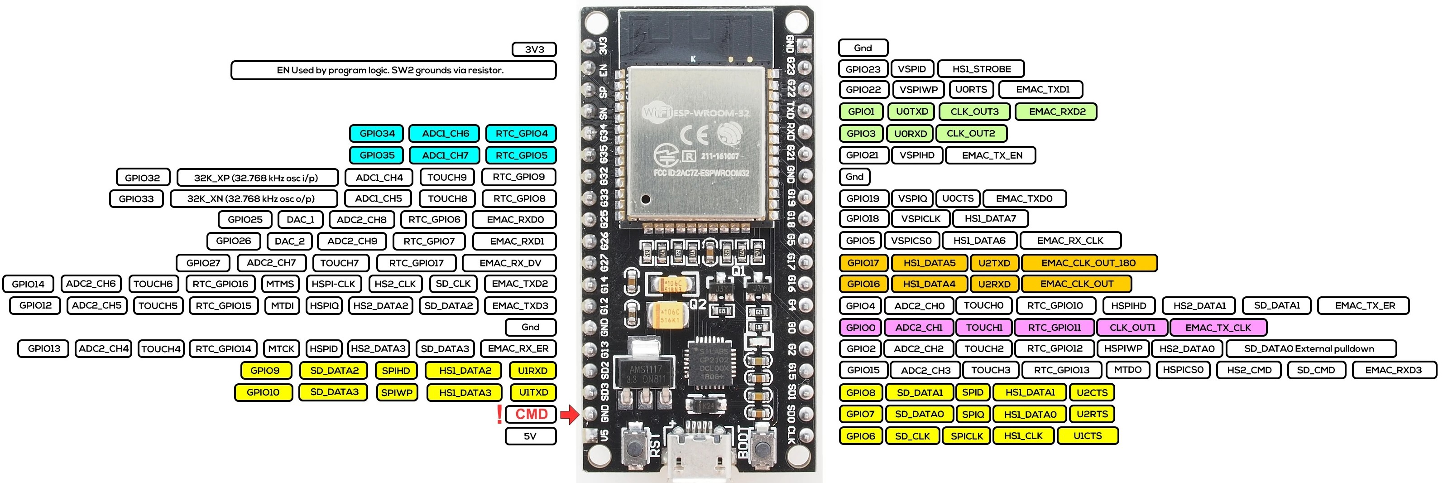
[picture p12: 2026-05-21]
Datasheets/ESP32.png

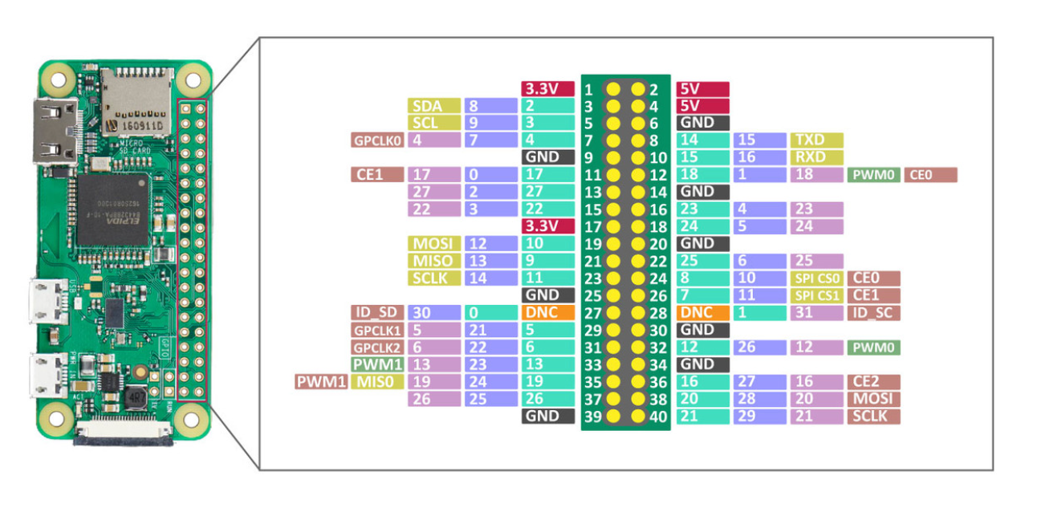
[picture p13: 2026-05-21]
Datasheets/RaspberryPiZero2W/RASPBERRY PI ZRO 2 W.png

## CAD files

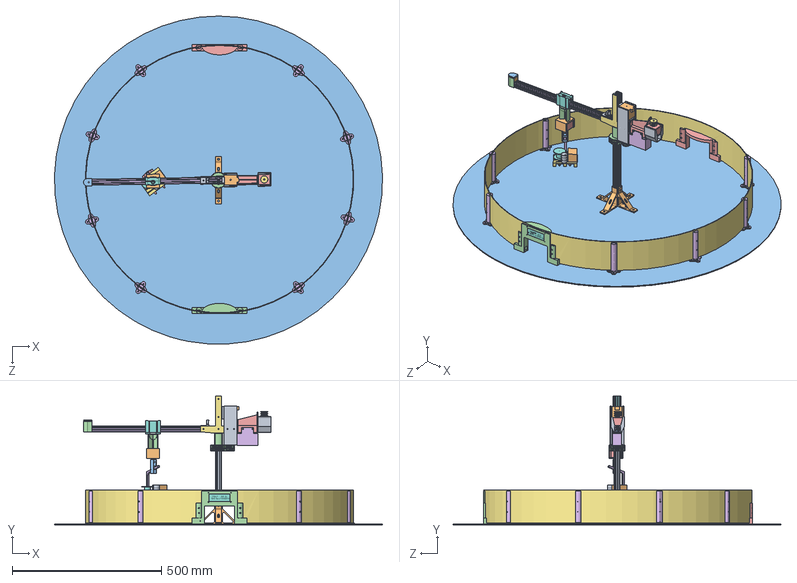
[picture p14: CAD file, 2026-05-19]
Diseños/Ensamblaje.SLDASM
1099.5 x 432.0 x 1099.1 mm
Pieza_1
Pieza_2 x 4
Pieza_3
Pieza_4
Pieza_5
Pieza_6
Pieza_7
Pieza_8
Pieza_9
Pieza_10_1 x 2
Pieza_10_2 x 2
Pieza_11
Pieza_12_1 x 2
Pieza_12_2 x 2
Pieza_13
Pieza_14_2
Pieza_15
Pieza_16
Pieza_17
Pieza_18
Pieza_19
Pieza_20
Pieza_21
Pieza_22
Pieza_23
Pieza_24
Pieza_25
Pieza_26
Pieza_27
Pieza_28
Pieza_29
Pieza_30
Pieza_31
Pieza_32
Pieza_33
Pieza_34
Pieza_35
Pieza_36 x 8
Pieza_37
Pieza_38

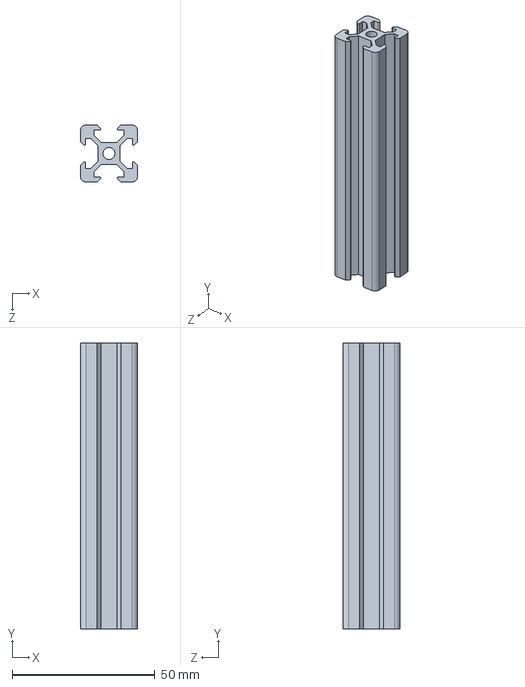
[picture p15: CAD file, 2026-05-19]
Diseños/Pieza_22.SLDPRT
20.0 x 100.0 x 20.0 mm

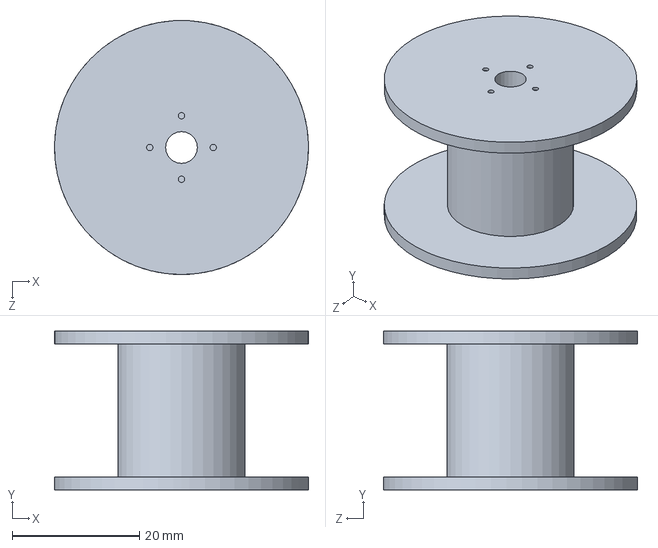
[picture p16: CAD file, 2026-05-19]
Diseños/Pieza_30.SLDPRT
40.0 x 25.0 x 40.0 mm

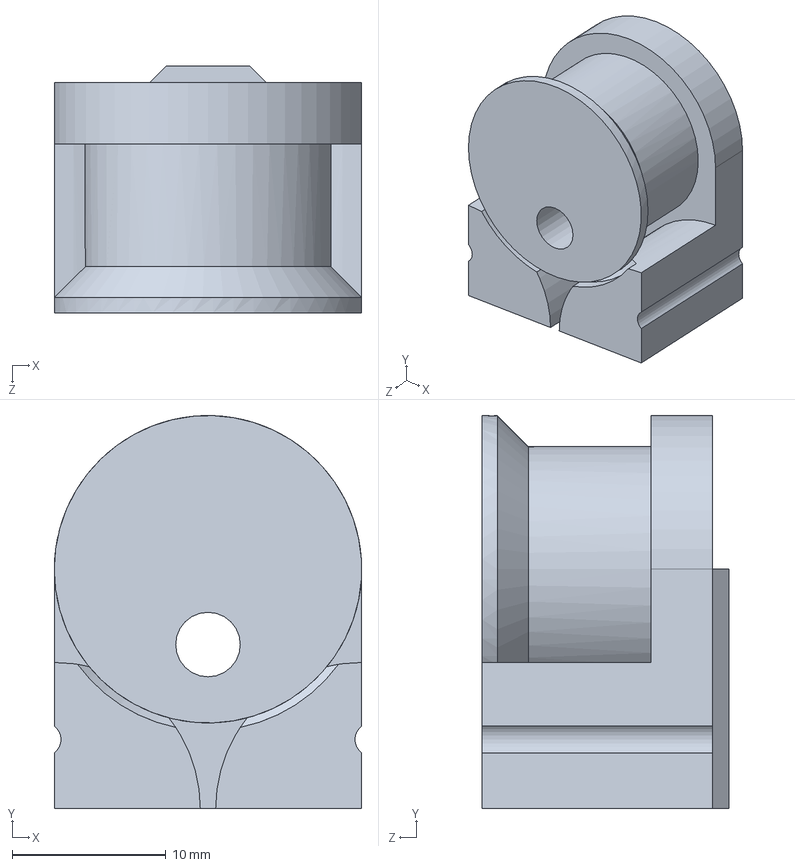
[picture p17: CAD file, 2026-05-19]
Diseños/Pieza_16.SLDPRT
20.0 x 25.6 x 16.1 mm

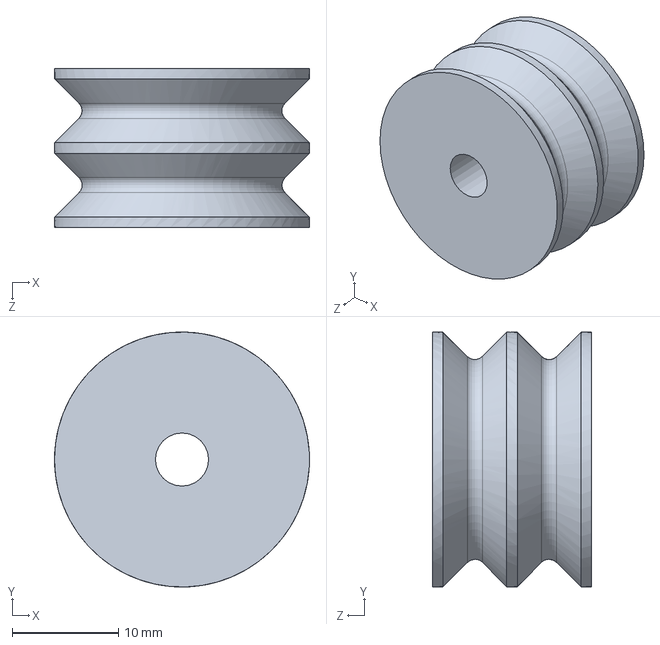
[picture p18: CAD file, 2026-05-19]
Diseños/Pieza_21.SLDPRT
24.0 x 24.0 x 15.0 mm

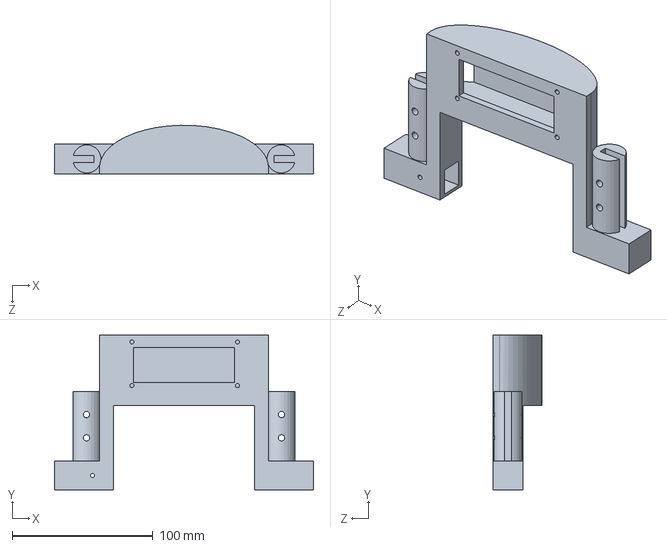
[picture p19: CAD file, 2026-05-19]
Diseños/Pieza_34.SLDPRT
184.0 x 110.0 x 34.5 mm

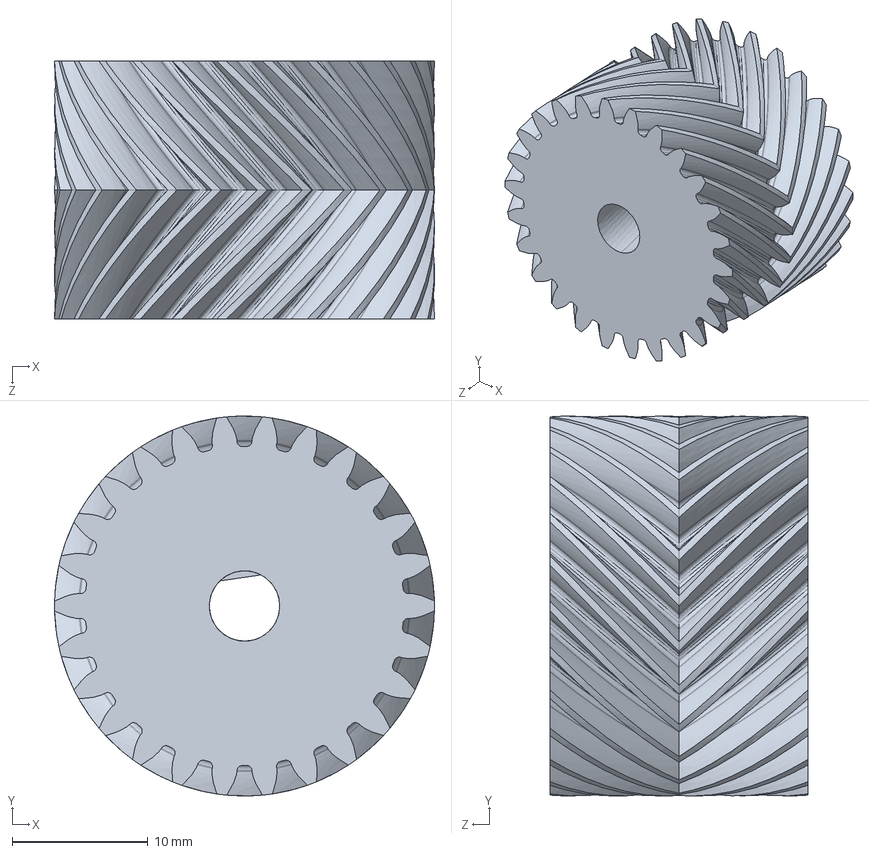
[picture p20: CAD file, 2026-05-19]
Diseños/Pieza_11.SLDPRT
28.0 x 28.0 x 19.0 mm

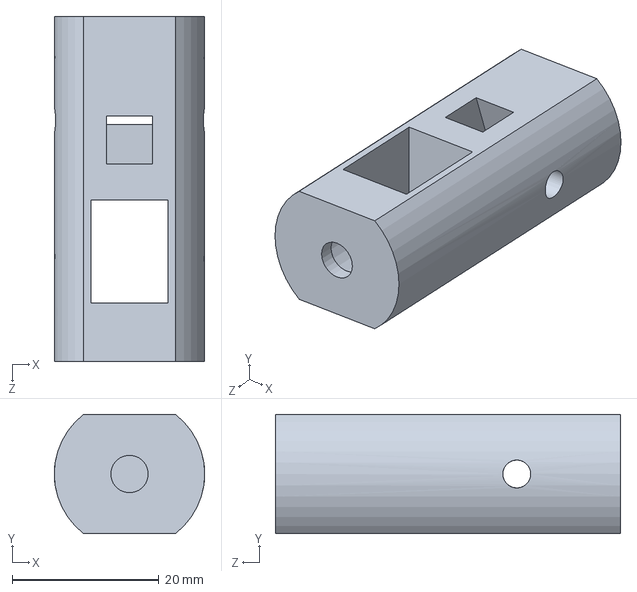
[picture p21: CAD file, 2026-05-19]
Diseños/Pieza_25.SLDPRT
20.5 x 16.2 x 47.0 mm

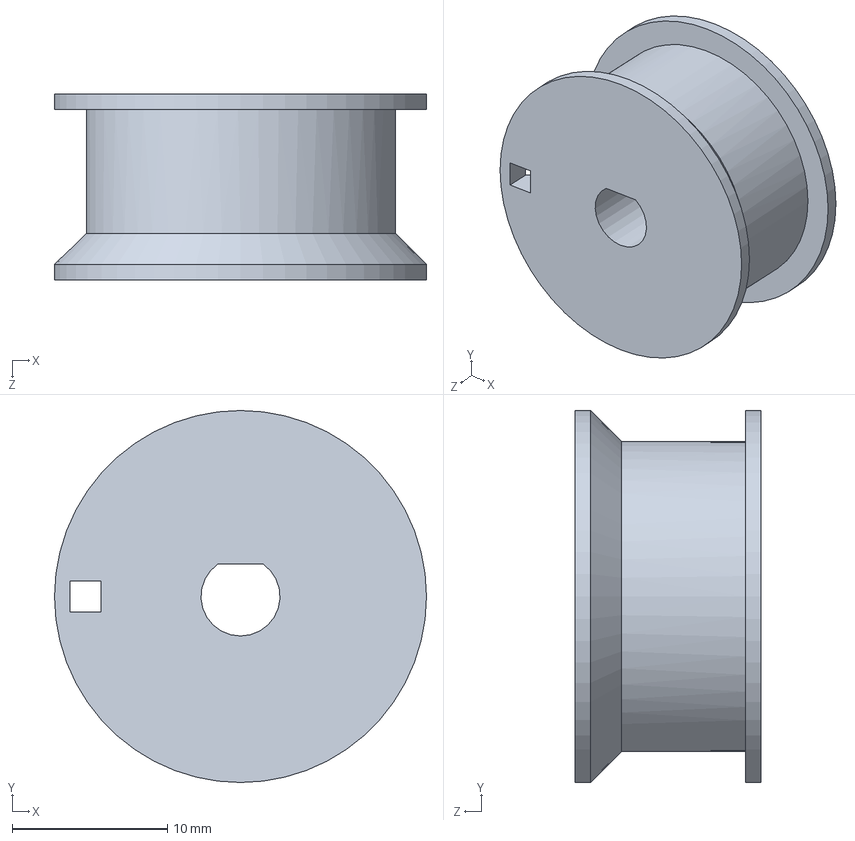
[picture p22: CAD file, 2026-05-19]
Diseños/Pieza_13.SLDPRT
24.0 x 24.0 x 12.0 mm

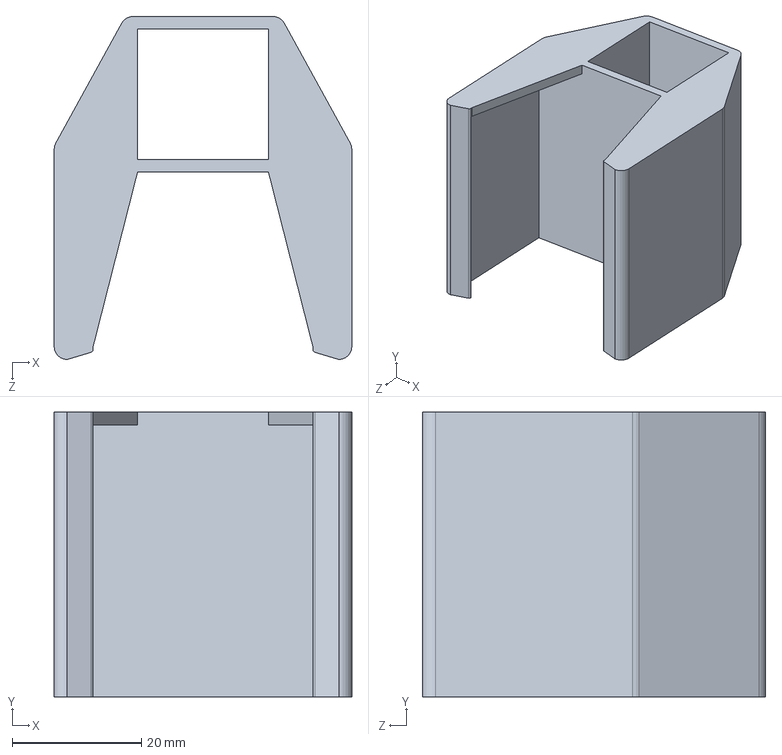
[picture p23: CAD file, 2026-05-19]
Diseños/Pieza_23.SLDPRT
46.0 x 44.0 x 53.0 mm

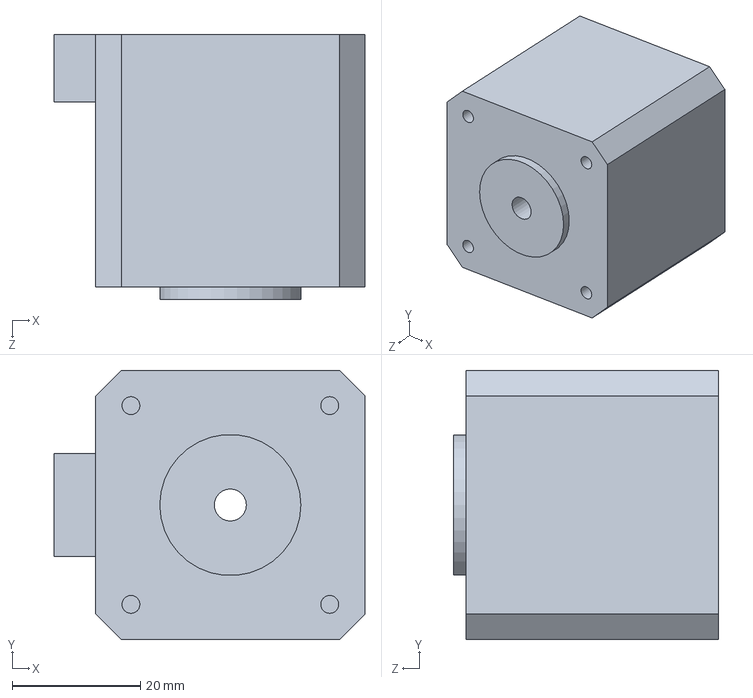
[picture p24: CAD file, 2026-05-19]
Diseños/Pieza_10_1.sldprt
48.5 x 42.0 x 41.3 mm

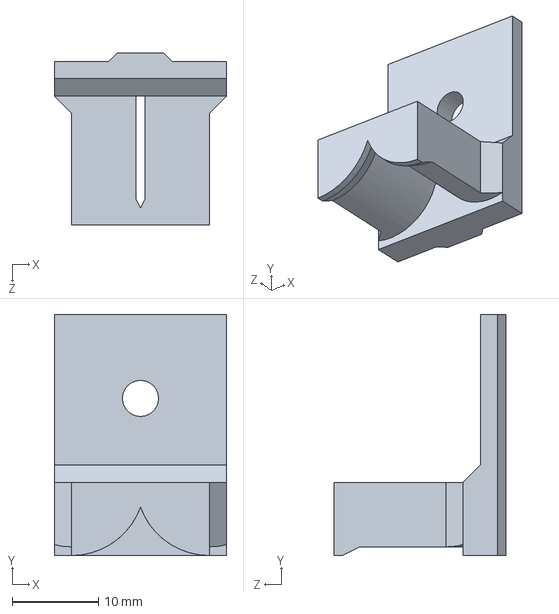
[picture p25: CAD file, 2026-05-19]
Diseños/Pieza_15.SLDPRT
20.0 x 28.0 x 20.0 mm

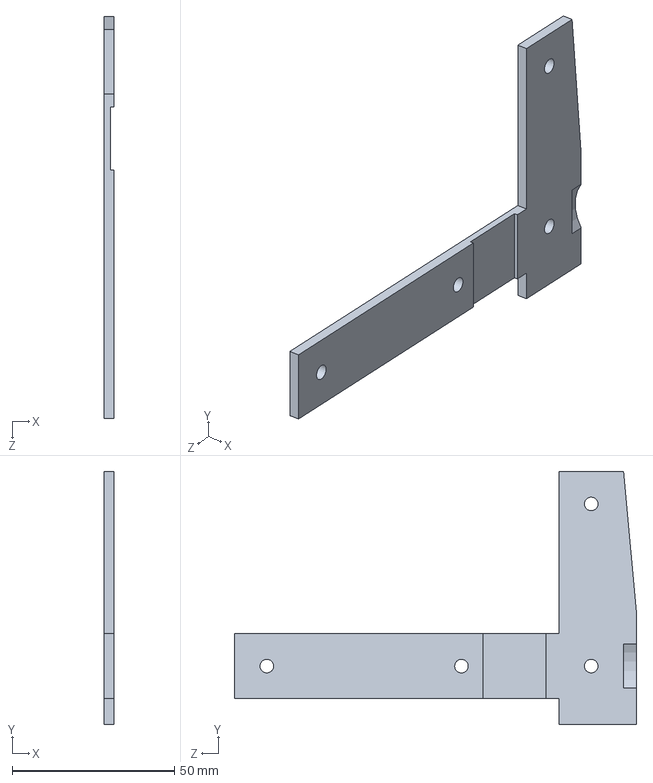
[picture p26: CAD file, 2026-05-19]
Diseños/Pieza_7.SLDPRT
3.00 x 78.0 x 124.0 mm

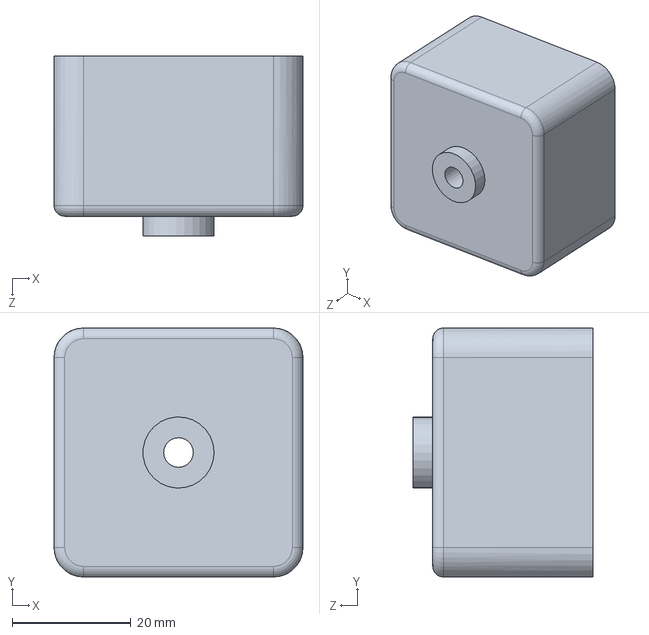
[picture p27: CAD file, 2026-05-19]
Diseños/Pieza_12_1.SLDPRT
42.0 x 42.0 x 30.3 mm

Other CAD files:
Diseños/Pieza_14_2.SLDPRT
Diseños/Pieza_1.SLDPRT
Diseños/Pieza_12_2.SLDPRT
Diseños/Pieza_2.SLDPRT
Diseños/Pieza_10_2.SLDPRT
Diseños/Pieza_14_1.SLDPRT
Diseños/Pieza_17.SLDPRT
Diseños/Pieza_18.SLDPRT
Diseños/Pieza_19.SLDPRT
Diseños/Pieza_20.SLDPRT
Diseños/Pieza_24.SLDPRT
Diseños/Pieza_26.SLDPRT
Diseños/Pieza_27.SLDPRT
Diseños/Pieza_28.SLDPRT
Diseños/Pieza_29.SLDPRT
Diseños/Pieza_3.SLDPRT
Diseños/Pieza_31.SLDPRT
Diseños/Pieza_32.SLDPRT
Diseños/Pieza_33.SLDPRT
Diseños/Pieza_35.SLDPRT
Diseños/Pieza_36.SLDPRT
Diseños/Pieza_37.SLDPRT
Diseños/Pieza_38.SLDPRT
Diseños/Pieza_4.SLDPRT
Diseños/Pieza_5.SLDPRT
Diseños/Pieza_6.SLDPRT
Diseños/Pieza_8.SLDPRT
Diseños/Pieza_9.SLDPRT

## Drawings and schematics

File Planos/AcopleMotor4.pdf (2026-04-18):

D D

6

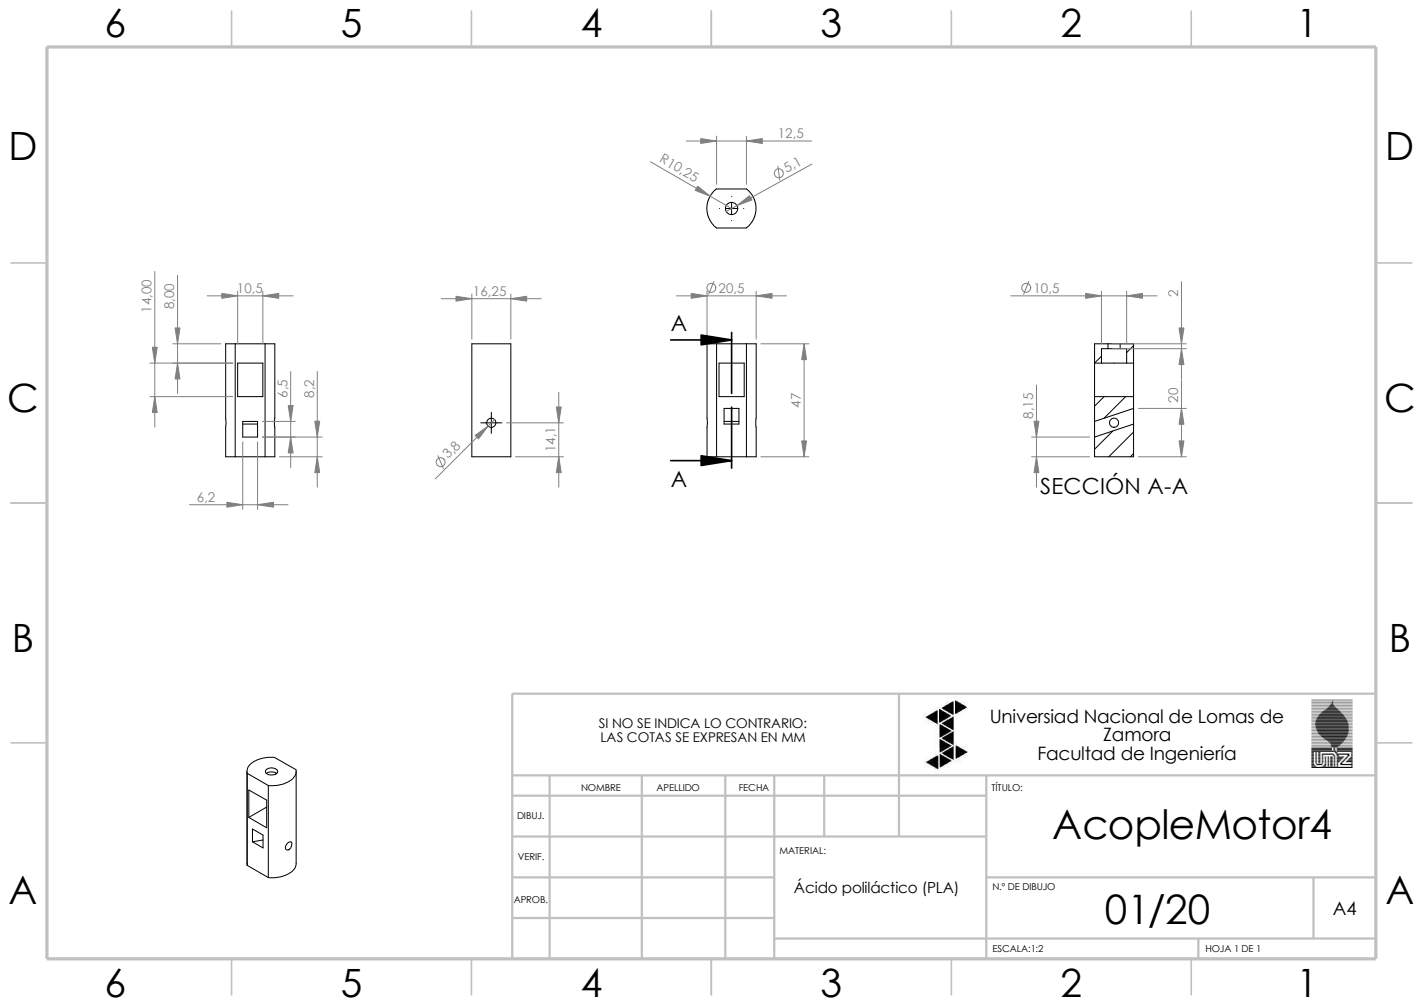
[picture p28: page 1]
ESCALA:1:2; HOJA 1 DE 1; SECCIÓN A-A ² ⁸,15

SI NO SE INDICA LO CONTRARIO: LAS COTAS SE EXPRESAN EN MM | Universiad Nacional de Lomas de Zamora Facultad de Ingeniería

NOMBRE | APELLIDO | FECHA | | | | TÍTULO: AcopleMotor4

DIBUJ.

VERIF. | | | | MATERIAL:

A A Ácido poliláctico (PLA)

APROB. | | | | | N.º DE DIBUJO | A4

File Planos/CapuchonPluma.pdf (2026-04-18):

D D

6

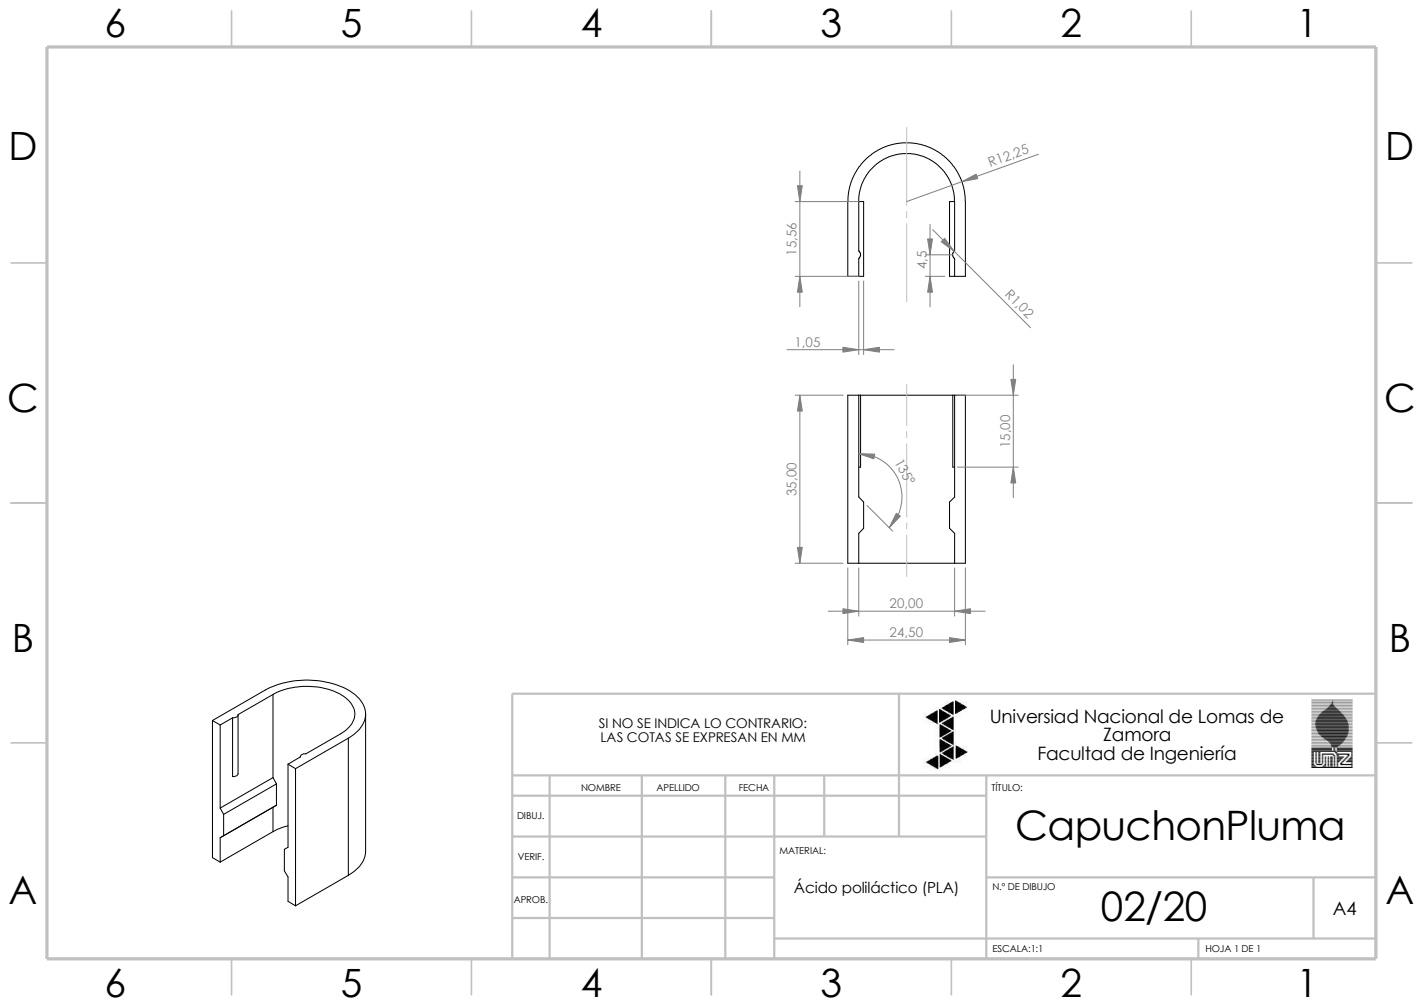
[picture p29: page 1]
ESCALA:1:1; HOJA 1 DE 1

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

NOMBRE | APELLIDO | FECHA | | | | TÍTULO: CapuchonPluma

DIBUJ.

VERIF. | | | | MATERIAL:

A A Ácido poliláctico (PLA)

APROB. | | | | | N.º DE DIBUJO | A4

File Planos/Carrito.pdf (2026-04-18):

D D

6

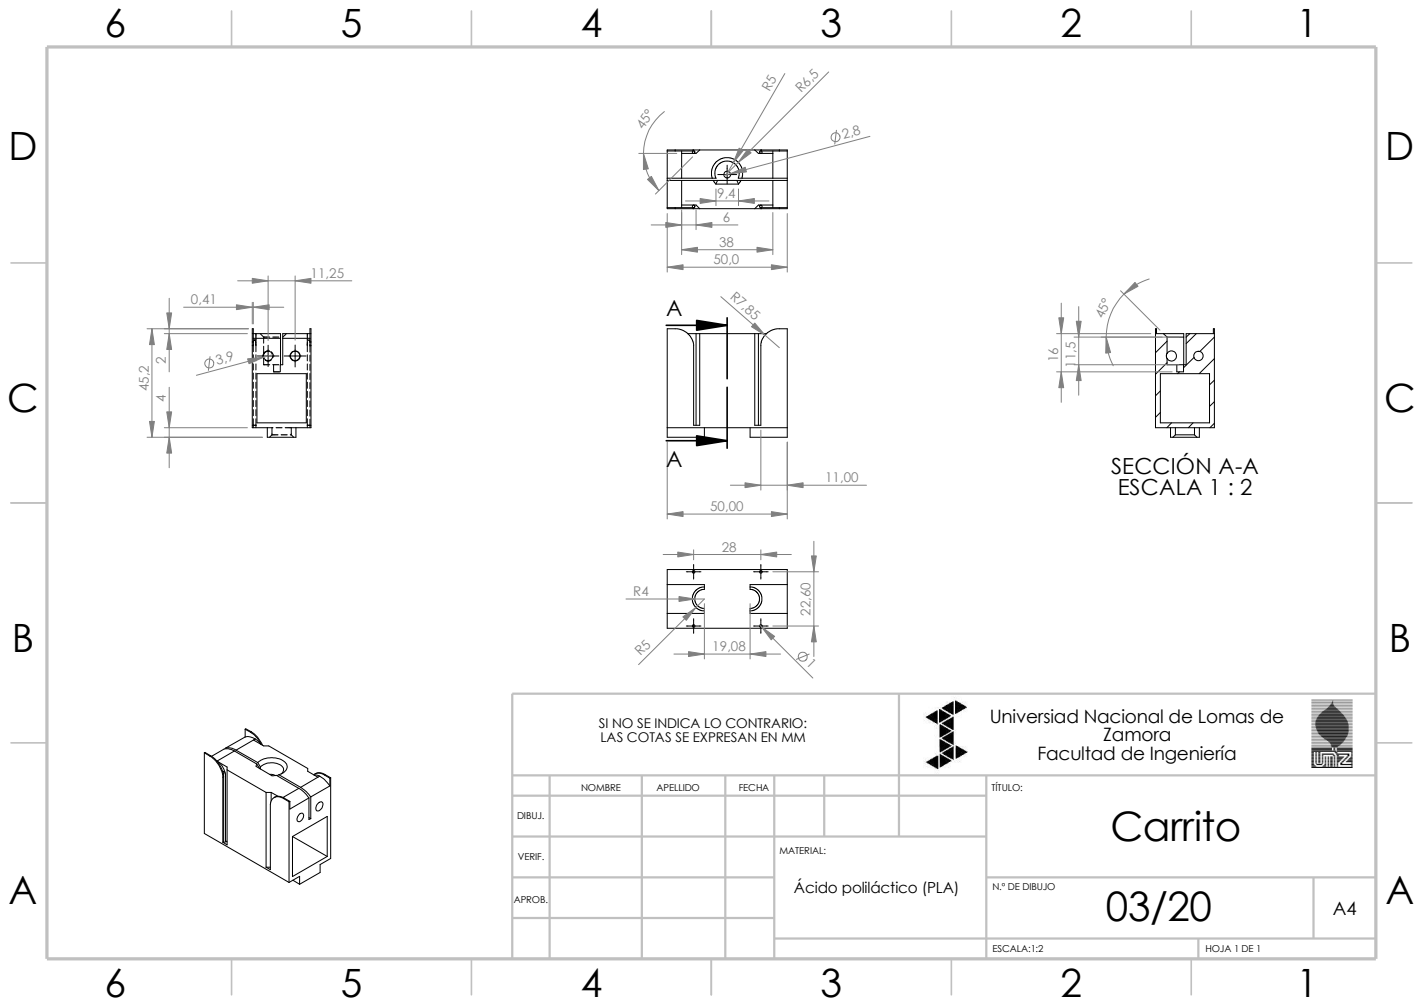
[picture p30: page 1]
ESCALA:1:2; HOJA 1 DE 1; SECCIÓN A-A; ESCALA 1 : 2 ¹¹,5 16

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

NOMBRE | APELLIDO | FECHA | | | | TÍTULO: Carrito

DIBUJ.

VERIF. | | | | MATERIAL:

A A Ácido poliláctico (PLA)

APROB. | | | | | N.º DE DIBUJO 03/20 | A4

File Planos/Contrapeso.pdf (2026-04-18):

D D

6

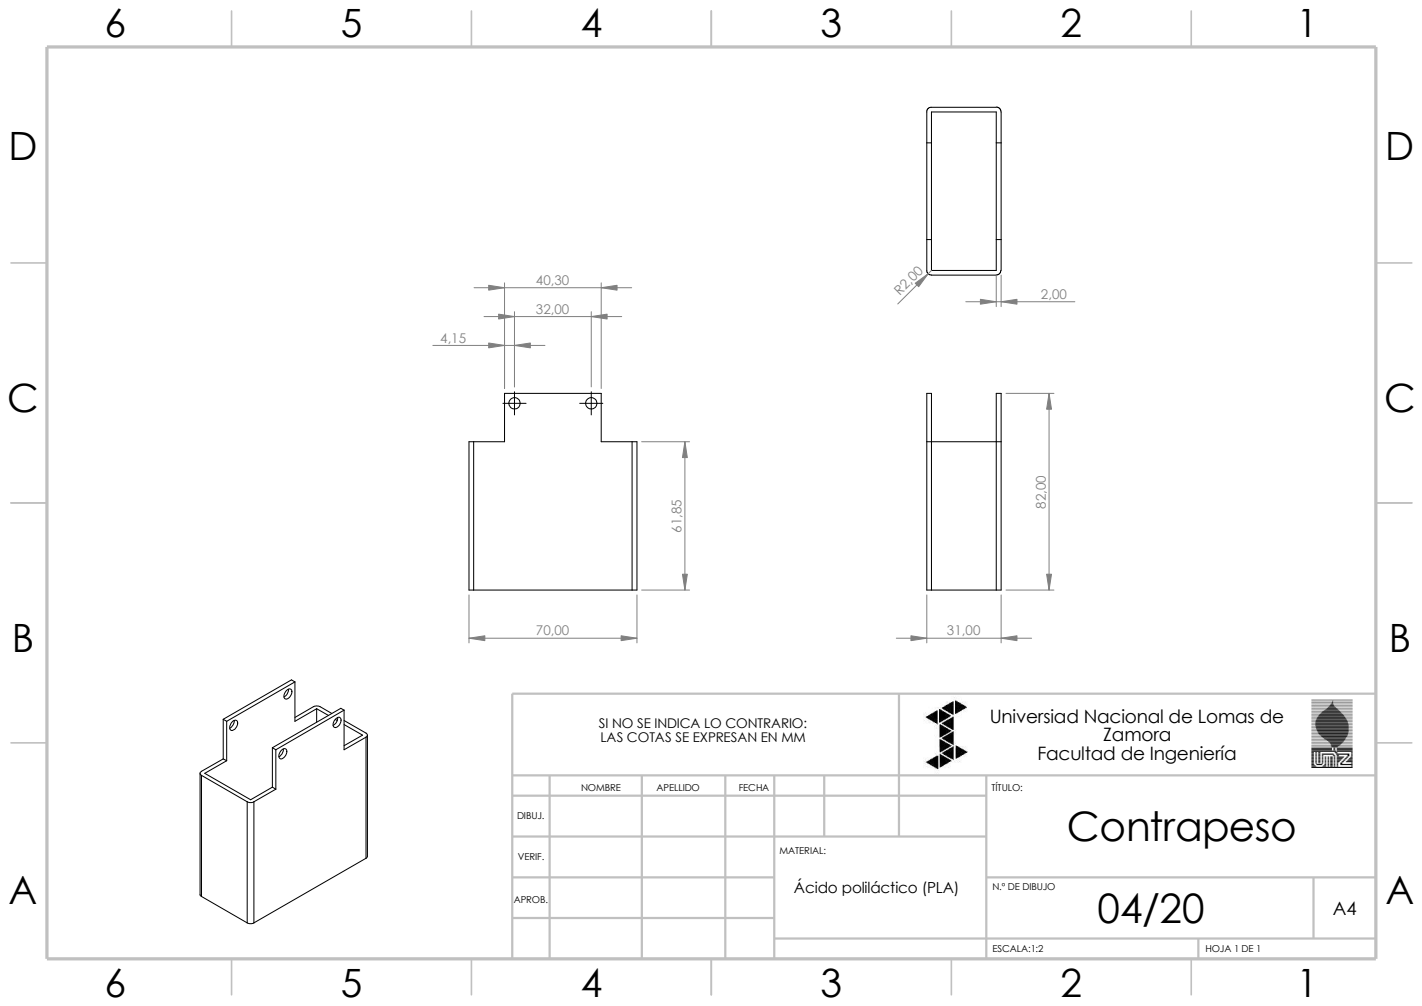
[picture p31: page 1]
ESCALA:1:2; HOJA 1 DE 1

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

NOMBRE | APELLIDO | FECHA | | | | TÍTULO: Contrapeso

DIBUJ.

VERIF. | | | | MATERIAL: Ácido poliláctico (PLA)

APROB. | | | | | N.º DE DIBUJO 04/20 | A4

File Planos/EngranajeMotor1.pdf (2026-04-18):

D D

6

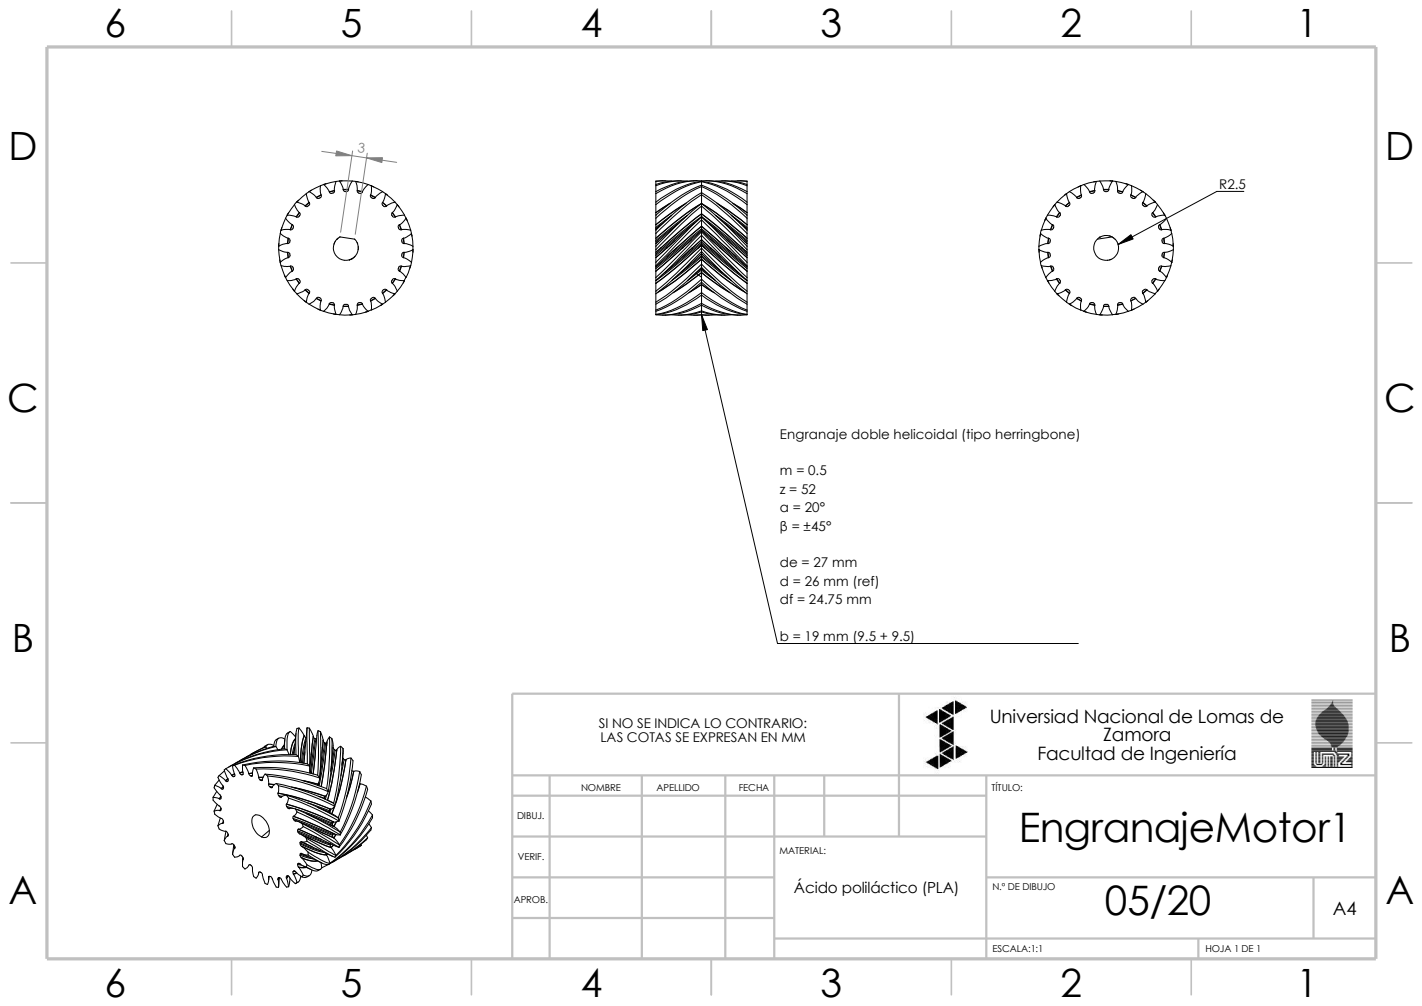
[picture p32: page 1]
ESCALA:1:1; HOJA 1 DE 1; de = 27 mm d = 26 mm (ref) df = 24.75 mm

Engranaje doble helicoidal (tipo herringbone)

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

NOMBRE | APELLIDO | FECHA | | | | TÍTULO: EngranajeMotor1

DIBUJ.

VERIF. | | | | MATERIAL:

A A Ácido poliláctico (PLA)

APROB. | | | | | 05/20 N.º DE DIBUJO | A4

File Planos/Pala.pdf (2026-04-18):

D D

6

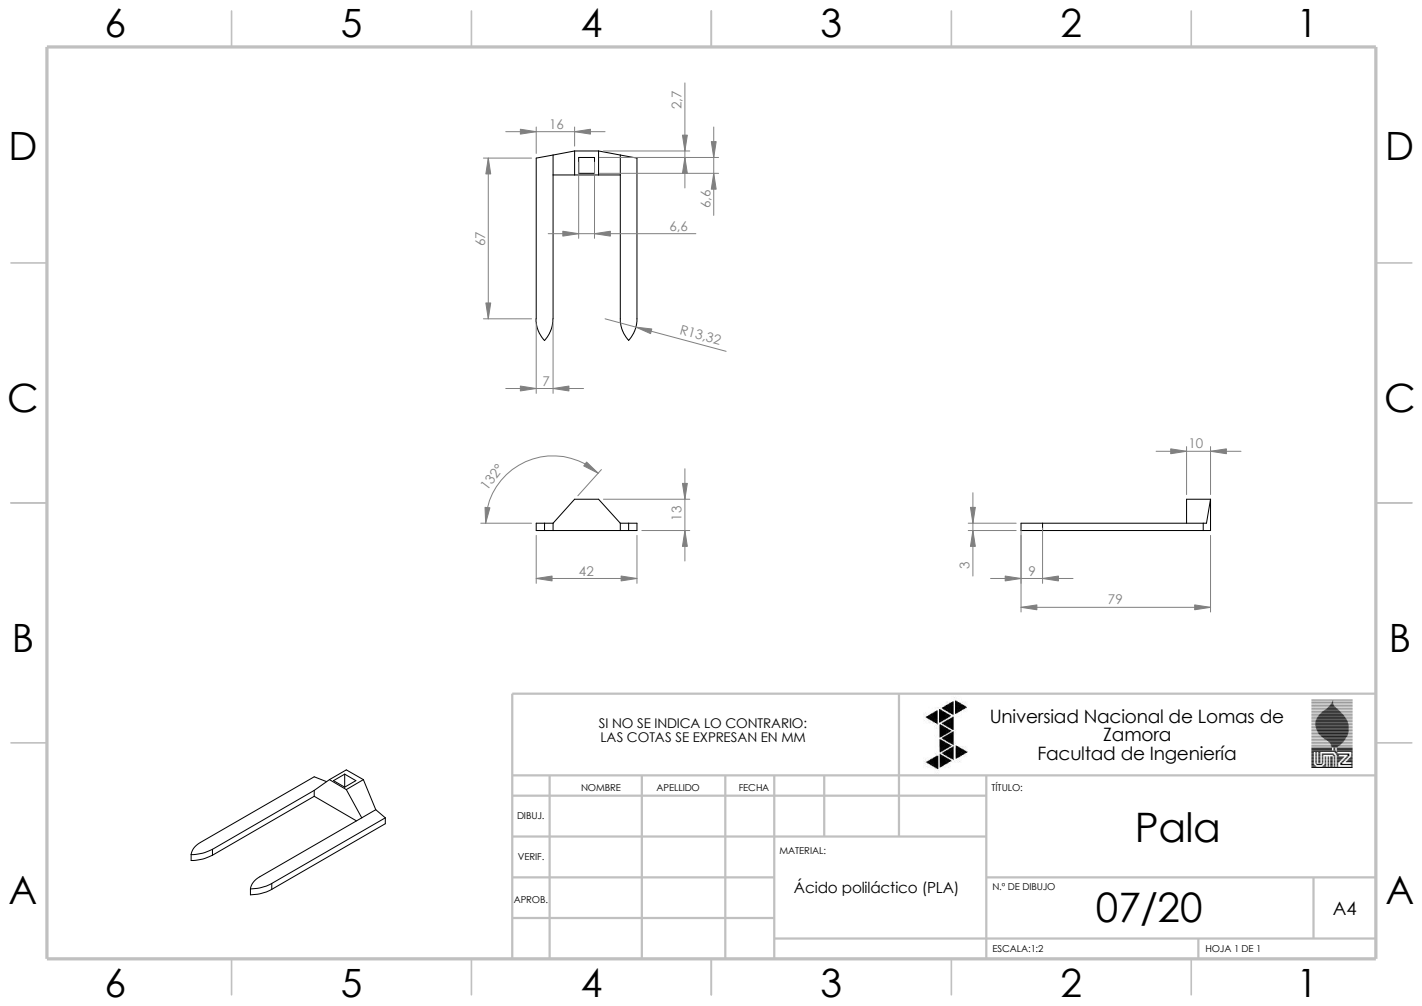
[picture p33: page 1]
ESCALA:1:2; HOJA 1 DE 1

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

NOMBRE | APELLIDO | FECHA | | | | TÍTULO: Pala

DIBUJ.

VERIF. | | | | MATERIAL:

A A Ácido poliláctico (PLA)

APROB. | | | | | N.º DE DIBUJO 07/20 | A4

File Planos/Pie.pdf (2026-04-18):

D D

6

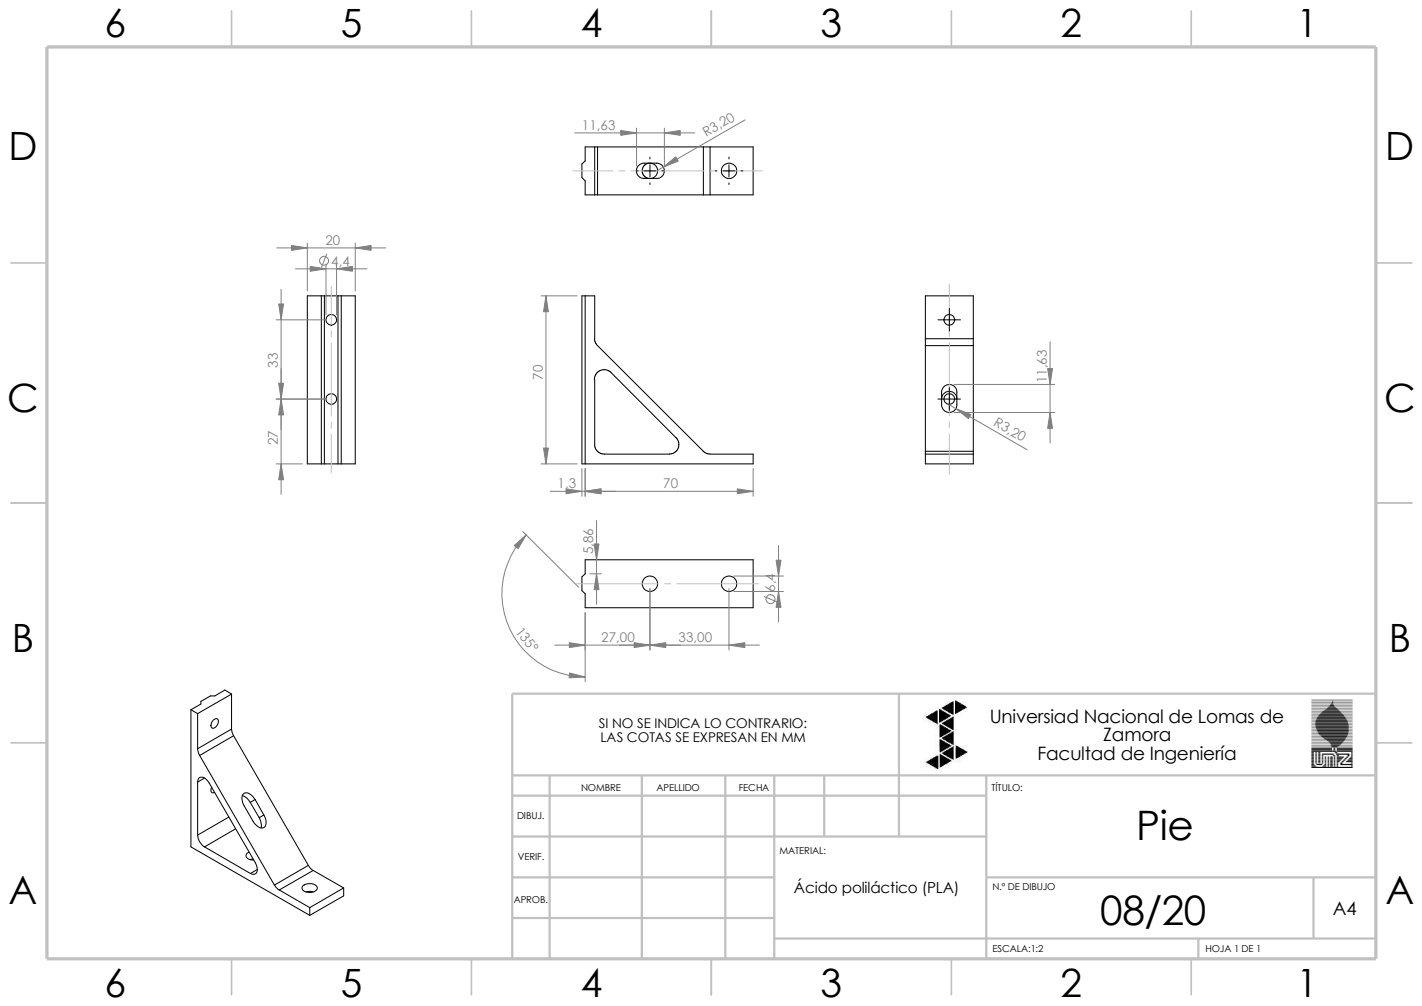
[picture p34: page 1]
ESCALA:1:2; HOJA 1 DE 1

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

NOMBRE | APELLIDO | FECHA | | | | TÍTULO: Pie

DIBUJ.

VERIF. | | | | MATERIAL:

A A Ácido poliláctico (PLA)

APROB. | | | | | N.º DE DIBUJO 08/20 | A4

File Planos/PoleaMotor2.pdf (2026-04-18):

D D

6

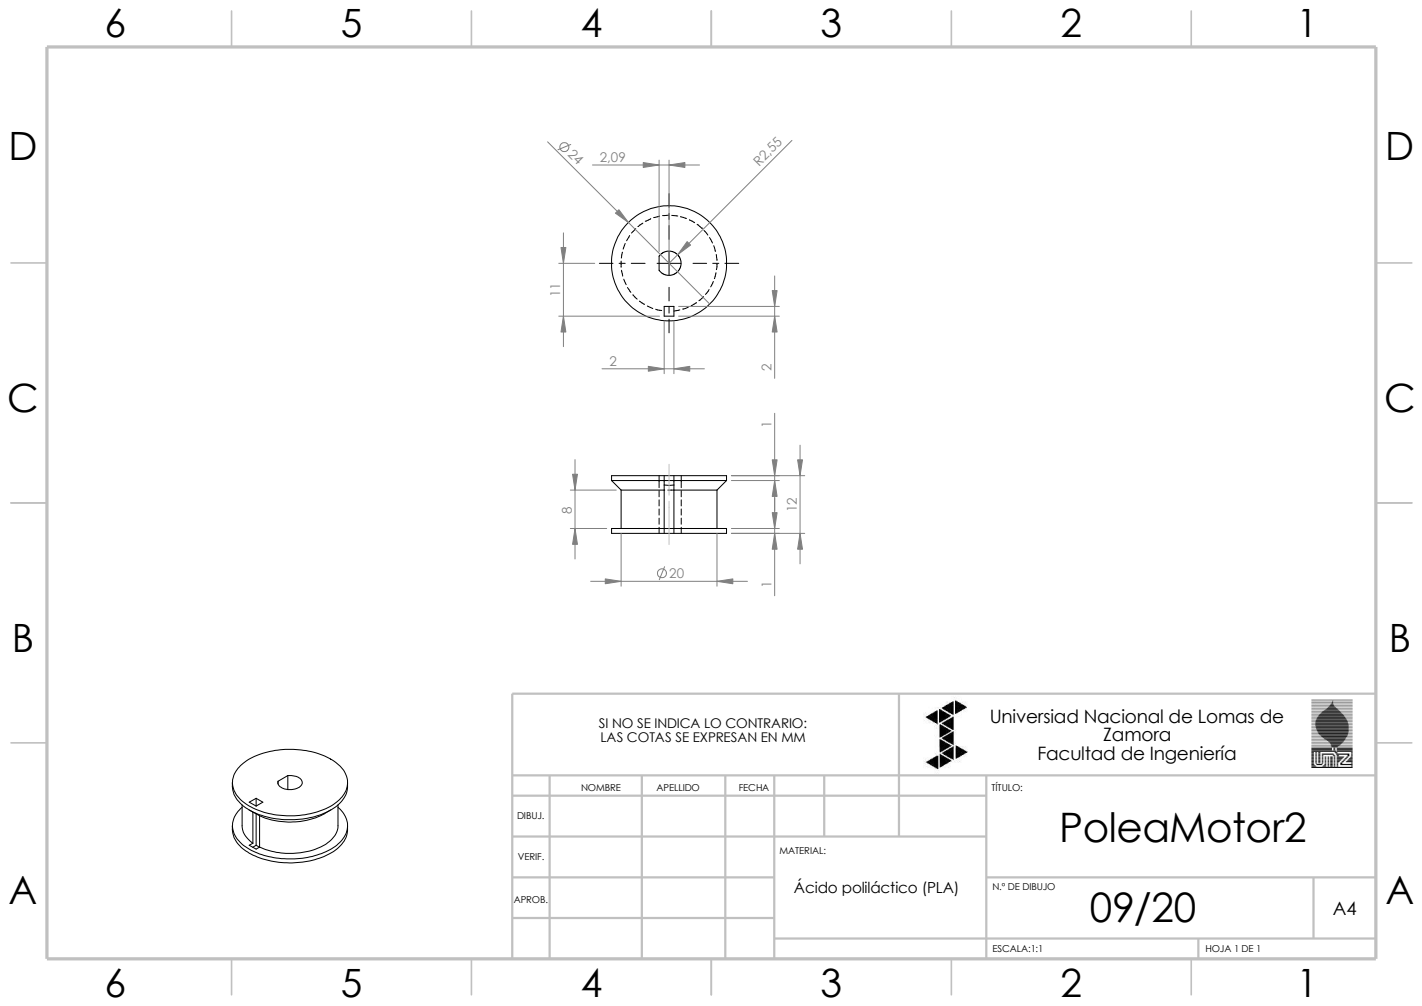
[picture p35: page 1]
ESCALA:1:1; HOJA 1 DE 1

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

NOMBRE | APELLIDO | FECHA | | | | TÍTULO: PoleaMotor2

DIBUJ.

VERIF. | | | | MATERIAL:

A A Ácido poliláctico (PLA)

APROB. | | | | | N.º DE DIBUJO 09/20 | A4

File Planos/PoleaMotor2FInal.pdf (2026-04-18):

D D

6

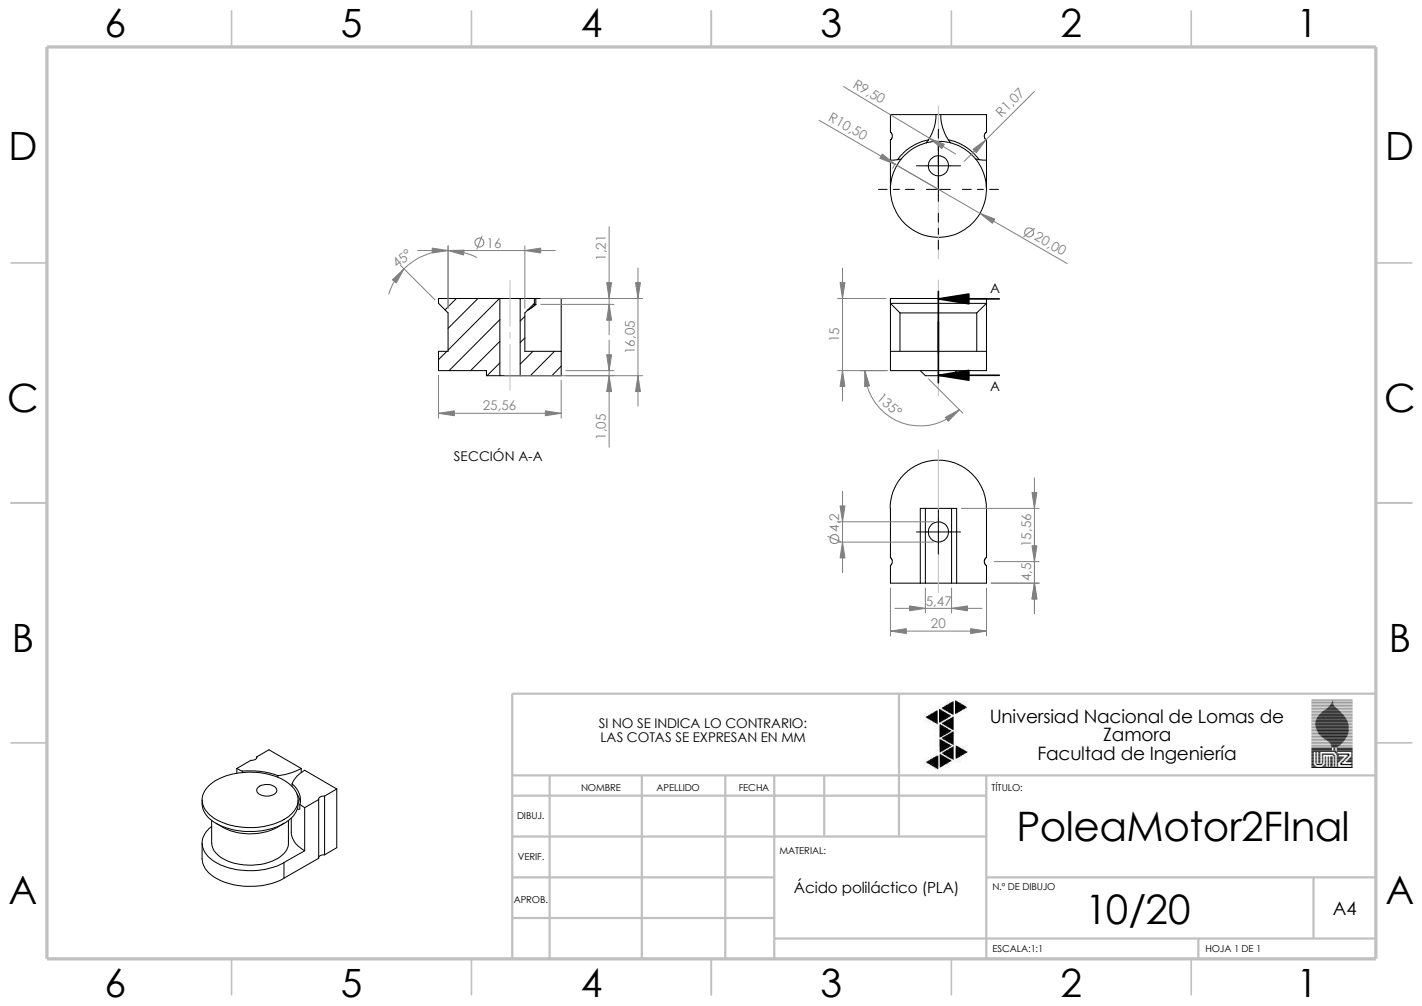
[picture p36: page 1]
ESCALA:1:1; HOJA 1 DE 1; SECCIÓN A-A

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

NOMBRE | APELLIDO | FECHA | | | | TÍTULO: PoleaMotor2FInal

DIBUJ.

VERIF. | | | | MATERIAL:

A A Ácido poliláctico (PLA)

APROB. | | | | | N.º DE DIBUJO | A4

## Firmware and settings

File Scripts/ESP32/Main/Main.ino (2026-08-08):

/*
 * PROYECTO GRÚA ROBOTICA AUTOMATIZADA
 */
#include "Config.h"
#include "Motor.h"

StepperMotor motorA(PINS_A, SPEED_A, DEG_A);
StepperMotor motorB(PINS_B, SPEED_B, DEG_GENERIC);
StepperMotor motorC(PINS_C, SPEED_C, DEG_GENERIC);
StepperMotor motorD(PINS_D, SPEED_D, DEG_GENERIC);

String inputString = "";
bool stringComplete = false;

enum EstadoGrua { ESPERANDO, MOVIENDO_ABD, MOVIENDO_C };
EstadoGrua estadoActual = ESPERANDO;

void parseCommand(String cmd);
void processSingleCommand(String singleCmd);

void setup() {
  Serial.begin(115200);
  delay(1000); 
  
  motorA.energize();
  motorB.energize();
  motorC.energize();
  motorD.energize();

  Serial.println("\n**************************************************");
  Serial.println("ESP32 CONECTADA");
  Serial.println("**************************************************\n");
}

void loop() {
  while (Serial.available()) {
    char inChar = (char)Serial.read();
    if (inChar == '\n') stringComplete = true;
    else inputString += inChar;
  }

  if (stringComplete) {
    inputString.trim();
    if (inputString.length() > 0) {
      
      // PARADA DE SEGURIDAD 
      if (inputString.equalsIgnoreCase("STOP")) {
        motorA.stop(); motorB.stop(); motorC.stop(); motorD.stop();
        Serial.println("\n!!!!!!!!!!!!!!!!!!!!!!!!!!!!!!!!!!!!!!!!!!!!!!!!!!");
        Serial.println("ALERTA: Comando 'STOP' recibido.");
        Serial.println("Sistema en espera.");
        Serial.println("!!!!!!!!!!!!!!!!!!!!!!!!!!!!!!!!!!!!!!!!!!!!!!!!!!\n");
        estadoActual = ESPERANDO; 
      } else {
        parseCommand(inputString);
      }
    }
    inputString = "";
    stringComplete = false;
  }

  // MÁQUINA DE ESTADOS HÍBRIDA (Se respeta la secuencia A,B,D -> C)
  switch (estadoActual) {
    case ESPERANDO: break;
    case MOVIENDO_ABD:
      motorA.update(); motorB.update(); motorD.update();
      if (!motorA.isBusy() && !motorB.isBusy() && !motorD.isBusy()) {
        if (motorC.isBusy()) estadoActual = MOVIENDO_C;
        else {
          Serial.println("Listo");
          estadoActual = ESPERANDO;
        }
      }
      break;
    case MOVIENDO_C:
      motorC.update();
      if (!motorC.isBusy()) {
        Serial.println("Listo");
        estadoActual = ESPERANDO;
      }
      break;
  }
}

void parseCommand(String cmd) {
  Serial.println("==================================================");
  Serial.print("Orden recibida: "); Serial.println(cmd);
  Serial.println("--------------------------------------------------");

  int startIdx = 0;
  int endIdx = cmd.indexOf(';');
  while (endIdx != -1) {
    processSingleCommand(cmd.substring(startIdx, endIdx));
    startIdx = endIdx + 1;
    endIdx = cmd.indexOf(';', startIdx);
  }
  processSingleCommand(cmd.substring(startIdx));

  if (motorA.isBusy() || motorB.isBusy() || motorD.isBusy()) estadoActual = MOVIENDO_ABD;
  else if (motorC.isBusy()) estadoActual = MOVIENDO_C;
  else Serial.println("Listo");
}

void processSingleCommand(String singleCmd) {
  int separator = singleCmd.indexOf(':');
  
  if (separator != -1) {
    char id = singleCmd.charAt(0);
    // Buscamos si existe el marcador de velocidad "-V"
    int velocityMarker = singleCmd.indexOf("-V");
    
    float val = 0.0;
    int newSpeed = -1;

    // Si encontramos "-V", separamos los grados de la velocidad
    if (velocityMarker != -1) {
      val = singleCmd.substring(separator + 1, velocityMarker).toFloat();
      newSpeed = singleCmd.substring(velocityMarker + 2).toInt();
    } else {
      // Si no hay "-V", solo leemos los grados
      val = singleCmd.substring(separator + 1).toFloat();
    }

    // Aplicamos los cambios al motor correspondiente
    switch(id) {
      case 'A': 
        if (newSpeed > 0) motorA.setSpeed(newSpeed);
        motorA.setTargetDegrees(val); 
        break;
      case 'B': 
        if (newSpeed > 0) motorB.setSpeed(newSpeed);
        motorB.setTargetDegrees(val); 
        break;
      case 'C': 
        if (newSpeed > 0) motorC.setSpeed(newSpeed);
        motorC.setTargetDegrees(val); 
        break;
      case 'D': 
        if (newSpeed > 0) motorD.setSpeed(newSpeed);
        motorD.setTargetDegrees(val); 
        break;
    }
  }
}

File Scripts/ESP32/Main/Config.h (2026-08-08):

#ifndef CONFIG_H
#define CONFIG_H
#include <Arduino.h>

// --- PINES: (STEP, DIR) ---
const int PINS_A[2] = {13, 14}; // Brazo  
const int PINS_B[2] = {27, 26}; // Carro  
const int PINS_C[2] = {25, 33}; // Gancho 
const int PINS_D[2] = {32, 4};  // Giro   

// --- VELOCIDADES DE INICIO (Por defecto al encender) ---
const int SPEED_A = 6500;  
const int SPEED_B = 2000;   
const int SPEED_C = 1000; 
const int SPEED_D = 3250; 

// --- MATEMÁTICA DE TRANSMISIÓN ---
const float BASE_STEPS = 3200.0; // Paso 1/16

// Motor A: Tiene reducción por engranajes 1:2
const float DEG_A = (BASE_STEPS * 2.0) / 360.0; 

// Motores B, C y D: Directos (o transmisión 1:1)
const float DEG_GENERIC = BASE_STEPS / 360.0; 

#endif

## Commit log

2025-06-21 Versión 1
    Primera carga de archivos
    [1-Montaje motor.SLDPRT, 4-Capuchon.SLDPRT, 4-Eje 1.SLDPRT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]
2026-03-21 Create ESP32
    Firmware del Microcontrolador
2026-03-21 Actualización de especificaciones técnicas y diagrama de componentes del sistema
2026-04-18 PlanesAndScrips
    Big data Load
    [1-Montaje motor.SLDPRT, 4-Capuchon.SLDPRT, 4-Eje 1.SLDPRT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]
2026-04-18 Documentación
    Documentación de propuestas, consultas y Gant
    [Diagrama Gantt-Coluccio,V - Gomez, F.xlsx]
2026-05-19 SolidWorks CAD models and final assembly
    [Ensamblaje.SLDASM, Pieza_1.SLDPRT, Pieza_10_1.sldprt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]
2026-08-08 Localize UI to Spanish and harden console logging
    Localize many UI strings (tabs, buttons, and status labels) from English to Spanish and adjust related tab/widget placements. Improve GlobalTab.add_log by importing html.escape, preserving ANSI stripping, handling multi-line messages, HTML-escaping each line, and inserting per-line colored prefixes to avoid duplicated prefixes and HTML injection. Also tidy cursor/scroll updates. These changes make the interface Spanish-friendly and more robust when rendering incoming log text.
2026-08-08 Expand vision subsystem documentation
    Restructure and expand the vision subsystem justification document with improved clarity and additional architectural details. Add engineering decisions summary to README with link to detailed justif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
2026-08-08 Add Visor operating instructions PDF
    Add Datasheets/Visor_operating_instructions_de_en_fr_es_it_zh_07.pdf — a multi-language (de, en, fr, es, it, zh) operating instructions datasheet. Adds the binary PDF file to the Datasheets directory.
2026-08-08 Add ESP32 asd.xlsx spreadsheet
    [asd.xlsx]
2026-08-08 a
    a
    [asd.xlsx]
2026-08-09 Update hardware specs in README
    Change stepper motor driver from L298N to A4988 and add LM2596 step-down regulator to the hardware components table.
2026-08-09 Add dedicated Acknowledgments section
    Reorganize and expand acknowledgments in README. Move acknowledgment content into a dedicated section with details about eMove Solutions S.A. (vision system loan) and IDEA3D Impresiones (3D printing 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
2026-08-09 Actualizar README: costos y añadir imagen VISOR
    Ajusta precios y subtotales en el presupuesto (LM2596, perfilería, rodamiento axial, manufactura aditiva) y recalcula totales del proyecto. Clarifica que el SensoPart VISOR fue cedido en préstamo y r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
2026-08-09 Refactor HMI, TTpower, SEpower and cinematica
    Large refactor improving robustness and UX across PC and RaspberryPi scripts. TTpower: add signal handling, graceful shutdown, keepalive sockets, camera reconnection, voice activation workflow, inter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
2026-08-17 Add design calculations and update README
    Add a new Doc/Calculos.md containing comprehensive electrical and mechanical verification (motor/driver losses, power supply sizing, pin-level checks, stability and strength calculations, load vs radius, torque requirements). Remove placeholder Doc/ENLACE-AL-VIDEO. Update README: correct driver name to A4988 in schematic caption and add a reference/note linking to Doc/Calculos.md for the detailed calculations.
2026-08-17 Update project Gantt chart
    Updated the project Gantt diagram document to reflect revised scheduling details. This change keeps the Excel timeline aligned with the latest project planning information.
    [Diagrama Gantt-Coluccio,V - Gomez, F.xlsx]
2026-08-23 Actualizar diagrama de arquitectura
    Se reemplaza el bloque Mermaid del README por una imagen estática del diagrama de arquitectura del sistema. Esto mejora la legibilidad y mantiene la documentación con un artefacto visual más estable 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
2026-08-30 Add HMI styling, network config and calibration
    Introduce network config and a design system for the HMI, plus end-to-end calibration support. Added Scripts/PC/{config_red.py,config_red.json,estilo.py,calibracion.py} and integrated them into TTpower.py and main.py (UI redesign: navigation rail, global stylesheet, network dialog, calibration tab). SEpower.py now tracks PC IP, improves console handling, implements calibration commands and emits calibration/status lines. cinematica.py now supports per-point work heights (alturas.json), calibration poses, jog steps and validates ALTURA_MINIMA; FASE_CALIBRAR added. Also added calibration-related signals between SSHWorker/TTpower and the GUI.
    [SEpower.py, cinematica.py]
2026-09-08 Fix Valentin's LinkedIn URL in README
    Update Valentín Coluccio's LinkedIn badge URL in README.md to the correct profile (/valentin-coluccio/). No other changes were made.
